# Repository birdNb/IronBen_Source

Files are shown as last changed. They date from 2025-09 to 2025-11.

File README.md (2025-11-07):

 # IronBen 四足轮腿机器人开源项目（一个普通本科生的毕业设计）

 作品展示：
https://www.bilibili.com/video/BV18B9oYQEoy/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

开源内容包括：
  项目相关的所有结构源文件Structure、相关的所有控制代码code（上下位机）、PCB硬件源文件Hardware。

本作品同步在立创星火计划开源。
![Uploading 星火计划-透底黑.png…]()

同时我们组建了作品复刻交流群，方便解答同学们在复刻过程中遇到的各种问题。
复刻交流群
24b2e99905efaedd1b54d2c5730278c4
 ![Uploading 24b2e99905efaedd1b54d2c5730278c4.png…]()

低成本、全3D打印、STM32双核控制、支持体感/键鼠/图传三模控制的四足轮腿机器人。

---

## 1. 项目亮点
- **供电简单**：6S航模电池24V一次到位，DJI A板直降12V供8个总线舵机，再转5V供逻辑。
- **结构友好**：Z轴非承力，轴承+M5长螺丝定位；小腿过孔+尼龙扎带，长期运行不松动。
- **全开源**：3D文件、PCB、固件、上位机一键下载

---

## 2. 快速参数
| 项目 | 规格 |
|---|---|
| 整机尺寸 | 320×360×180 mm |参考
| 自重 | ≈2.7 kg（含电池） |
| 动力电池 | 格氏6S航模锂电池  24V 跟我的3D打印件有 |
| 主控 | STM32F407VET6 + 扩展板 |
| 手柄 | STM32G431 + 1.3"LCD + 双摇杆 |
| 执行器 | 8×FashionStar总线舵机12V + 4×DJI M3508轮毂电机 |
| 传感器 | JY901S陀螺仪×2、LoRa 433MHz |
| 通讯 | UART×3 / CAN×2 / ESP-NOW / 2.4G |所用通讯波特率均为115200

---
## 3. 文件结构
IronBen/
├── Structure/          # STL&STEP，打印方向已标
│   ├── Leg/           # 小腿-大腿-关节
│   ├── Body/          # 上下盖板、骨架
│   └── Wheel/         # 轮毂适配器
├── Hardware/
│   ├── Gerber_ExtBoard/  # 扩展板
│   ├── Gerber_CoreBoard/ # F407核心板
│   └── 手柄
├── code/
│   ├── F407_Chassis/  # 底盘信号+关节控制
│   ├── M3508_DJI/     # 3508电机驱动
│   └── Bodyfeeling/   # 体感手柄
│   └── cac-master/    # Jetson Nano图传+键鼠遥控
## 4. 一键BOM
| 名称 | 数量 | 团购暗号 | 备注 |
|---|---|---|---|
| FashionStar总线舵机12V | 8+2备 | 找杨经理13924656166说"四足轮腿机器人"可以优惠 | 
淘宝链接：[https://item.taobao.com/item.htm?id=645793030775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](https://item.taobao.com/item.htm?id=645793030775&spm=a21xtw.29178619.0.0&skuId=5216441462419)

| DJI M3508+C620套装 | 4套 | DJI官方 | 已含电机、电调、螺丝 |
| JY901S陀螺仪 | 2 | 维特智能 | 机身×1手柄×1 |
| STM32G431核心板 | 1 |   手柄主控 |
| 1.3"圆角LCD | 1 | SPI接口 | 易碎 |
| LoRa邮票孔433M | 4 | 一次性买齐，同批次 | 避免频段不同 |
| 偏心震动马达 | 3 | 10mm | 手柄反馈 |
| 摇杆ALPS | 2 | 带按键 | 与PCB封装匹配 |

五金&耗材见下节，全部内六角，电动螺丝刀扭矩≤3档，**禁止螺纹胶**！

---

## 5. 五金&耗材清单
| 规格 | 数量 | 用途 | 工具提醒 |
|---|---|---|---|
| PLA+2.0 | 3卷 | 全身结构 | 0.3层厚，30%填充 |
| M2×5内六角 | 50+ | 舵盘-舵机-3D件 | 威克士2代≤3档 |
| M3×10自攻 | 40+ | 上下盖板 | 预攻丝，滑丝换件 |
| M4×10内六角 | 20 | 骨架主梁 | 对角锁 |
| M5×40内六角 | 4 | 轮子+小腿+轴承 | 配625ZZ轴承×8 |
| 尼龙扎带 | 1包 | 小腿抱紧舵机 | 消除长期应力 |
| 硅胶线16AWG | 50cm | 电池→DJI A板 | 防压降 |
| 硅胶线20AWG | 30cm | 12V母线 | 同上 |

---

## 6. 供电接线图
24V电池(XT90)
├─DJI A板(24→12V)──12V母线──8×舵机
└─扩展板DC-DC(12→5V)──5V逻辑──F407+传感器

---

## 7. 装机流程（10分钟上手）
1. **打印**：按STL默认方向，0.3mm，无支撑。
2. **电子预检**：
   - 空载测12V/5V/3.3V正常 → 再插舵机。
   - 舵机ID逐个烧写，顺序0-7（右前→左后）。
3. **机械**：
   - 先装轮子+轴承+M5×40，再装小腿→尼龙扎带抱紧。
   - 所有螺丝**对角预紧→3档最终拧紧**。
4. **通讯**：
   - LoRa四块同时上电，长按SET 3s绿灯快闪即同频。
   - CAN终端电阻DJI A板已带，扩展板**勿重复焊**。
5. **上电自检**：
   - 蜂鸣器"滴"→舵机蓝→绿灯→M3508微抖，完成。

---

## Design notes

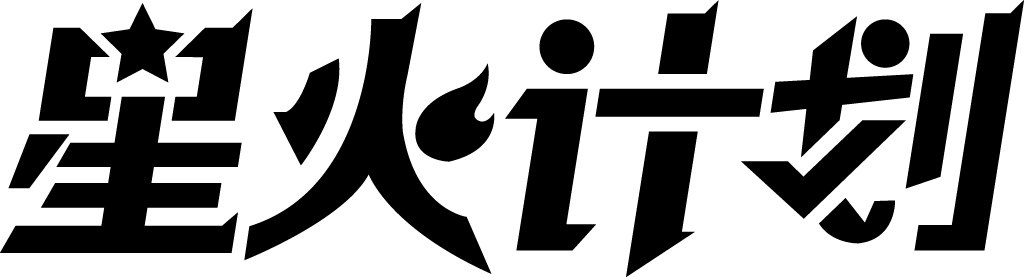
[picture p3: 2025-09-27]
星火计划-透底黑.png

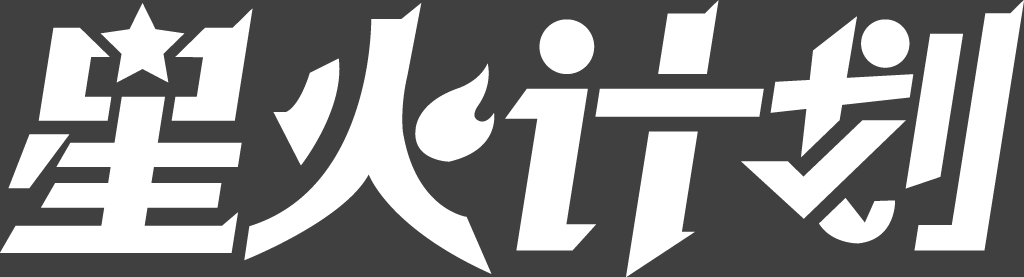
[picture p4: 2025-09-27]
星火计划-透底白.png

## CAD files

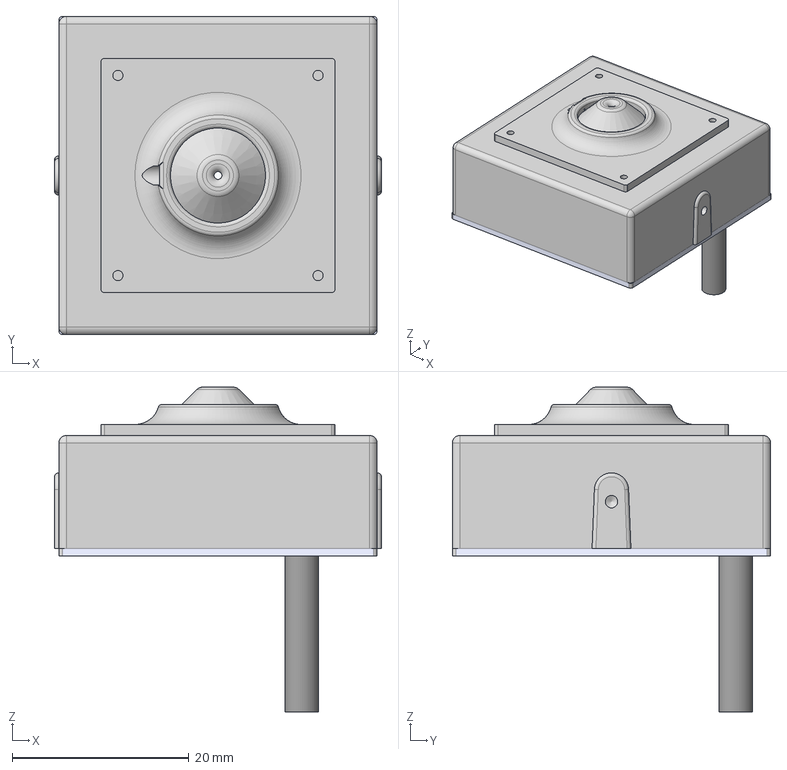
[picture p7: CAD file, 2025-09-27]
Structure/IronBen_print/摄像头.step
37.0 x 36.0 x 36.7 mm

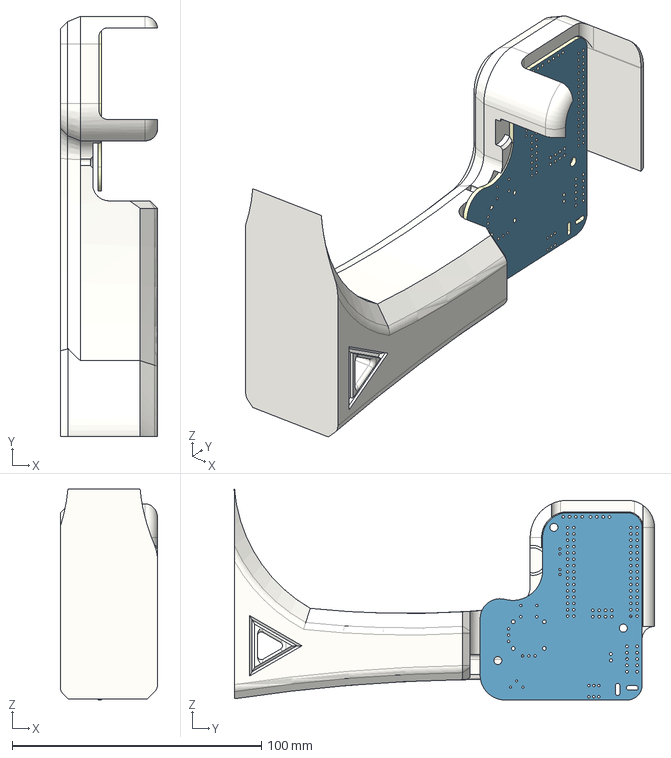
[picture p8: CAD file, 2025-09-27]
Structure/手柄.step
39.0 x 168.7 x 84.7 mm
手柄2.0
Board

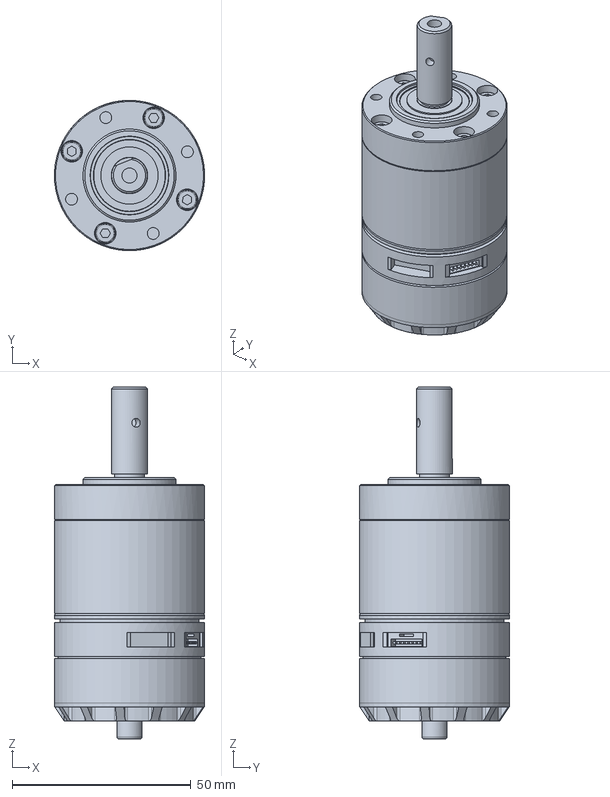
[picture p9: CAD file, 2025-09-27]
Structure/IronBen_print/3508电机.step
42.0 x 42.0 x 98.4 mm

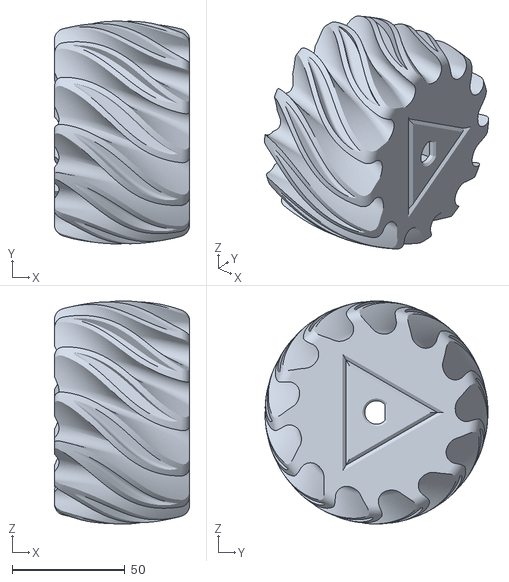
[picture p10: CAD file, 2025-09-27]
Structure/IronBen_print/轮本体.stl
60.0 x 98.9 x 99.0

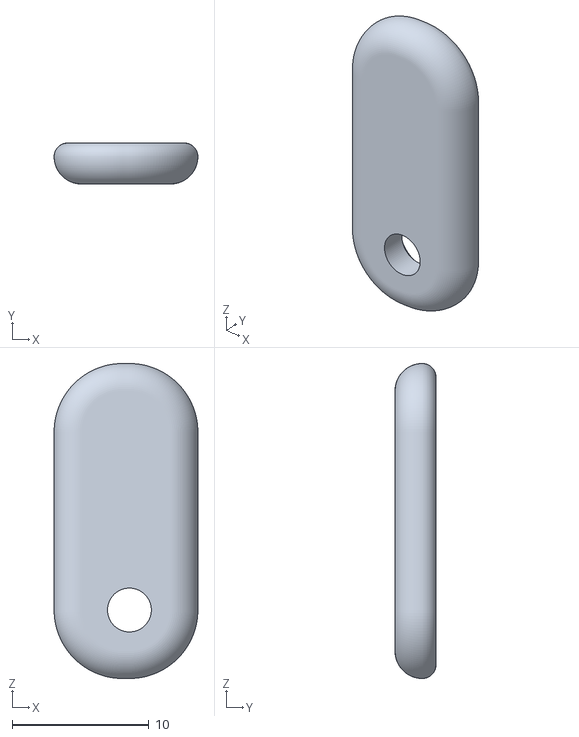
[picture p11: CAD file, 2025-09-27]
Structure/IronBen_print/旋转固定块.stl
10.5 x 3.00 x 23.0

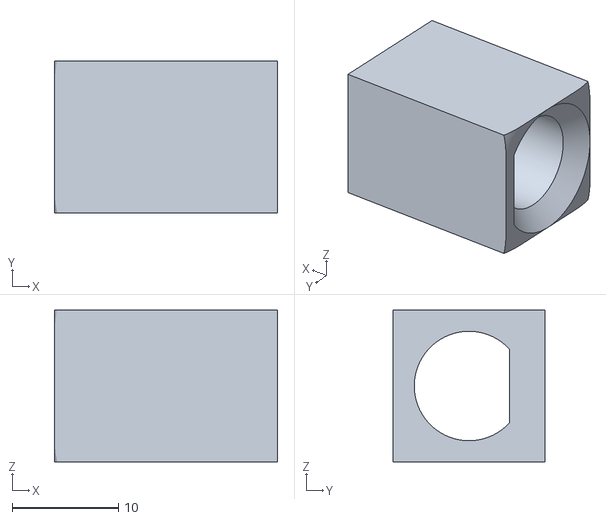
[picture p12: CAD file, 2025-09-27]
Structure/IronBen_print/旋转加强块.stl
21.0 x 14.3 x 14.3

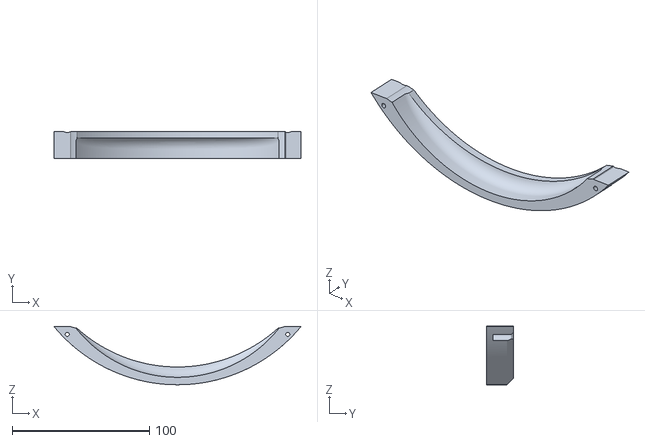
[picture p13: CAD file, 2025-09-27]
Structure/IronBen_print/后部眉盖.stl
180.0 x 20.0 x 42.7

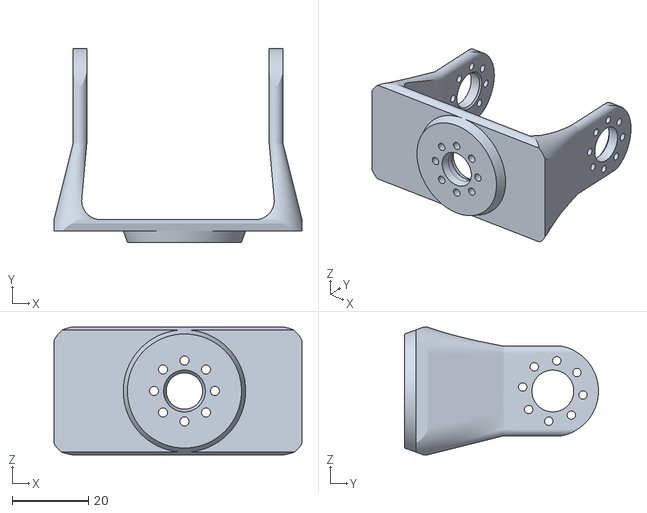
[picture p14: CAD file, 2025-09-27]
Structure/IronBen_print/云台T架.stl
65.2 x 51.0 x 33.6

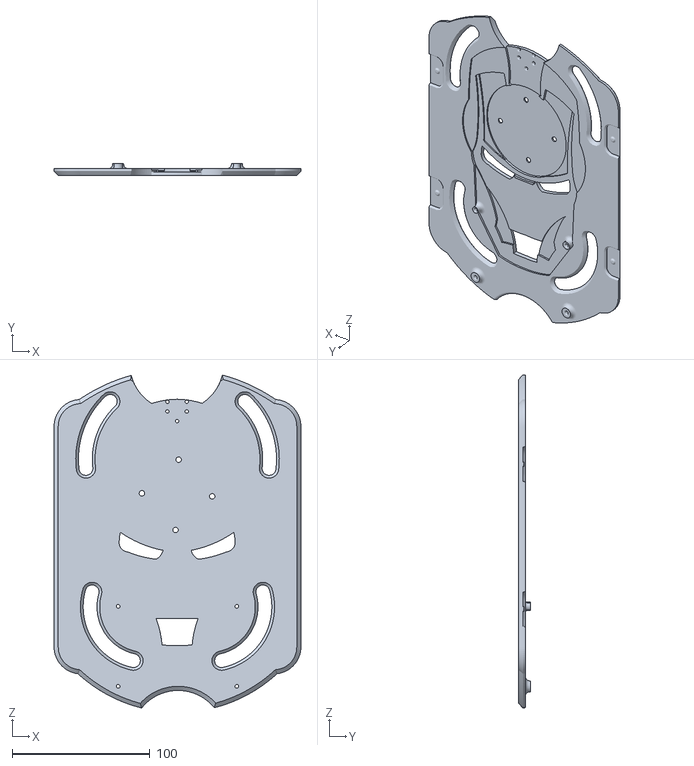
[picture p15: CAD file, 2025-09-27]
Structure/IronBen_print/顶板_jetson.stl
179.0 x 8.50 x 241.5

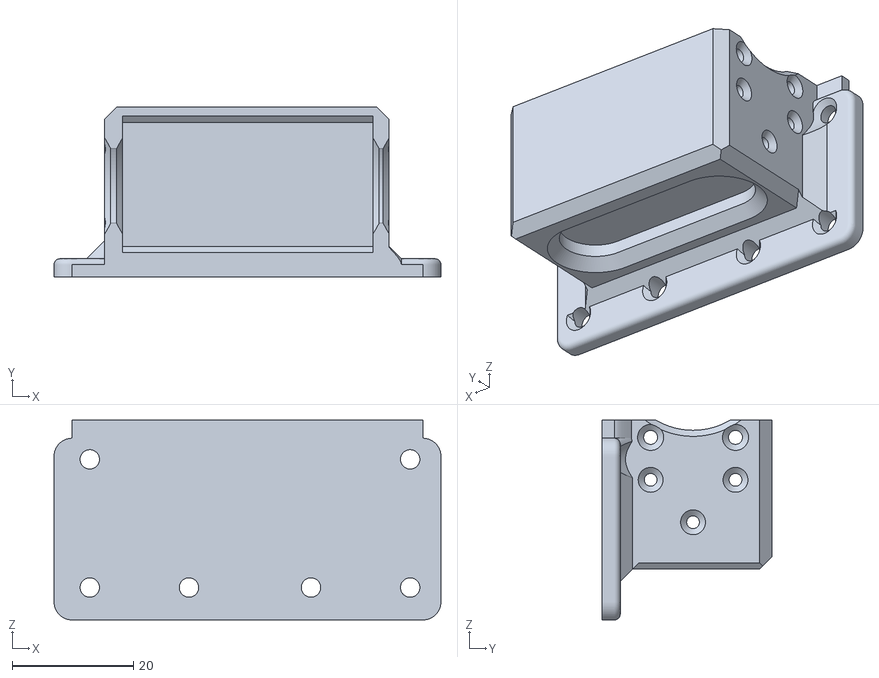
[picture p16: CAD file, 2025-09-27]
Structure/IronBen_print/舵机固定.stl
63.8 x 28.0 x 33.0

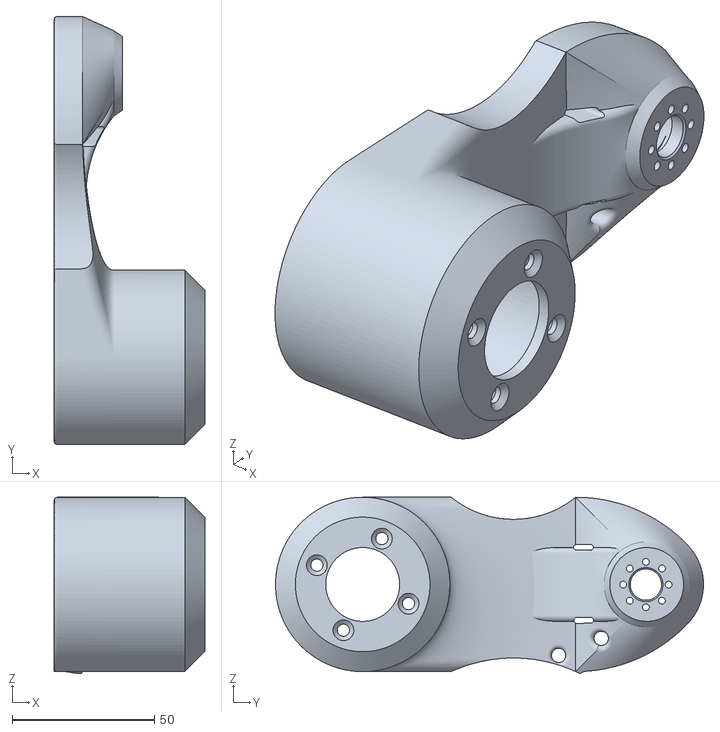
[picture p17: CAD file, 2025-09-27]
Structure/IronBen_print/左内.stl
53.0 x 150.7 x 62.1

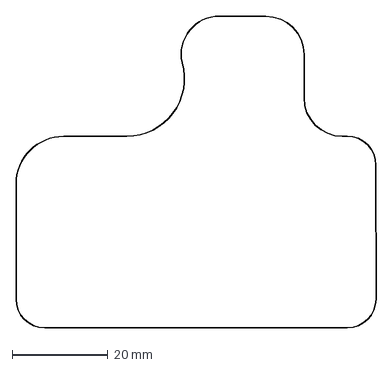
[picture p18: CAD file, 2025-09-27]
Structure/IronBen_print/handlepcb.dxf
75.2 x 65.1 mm

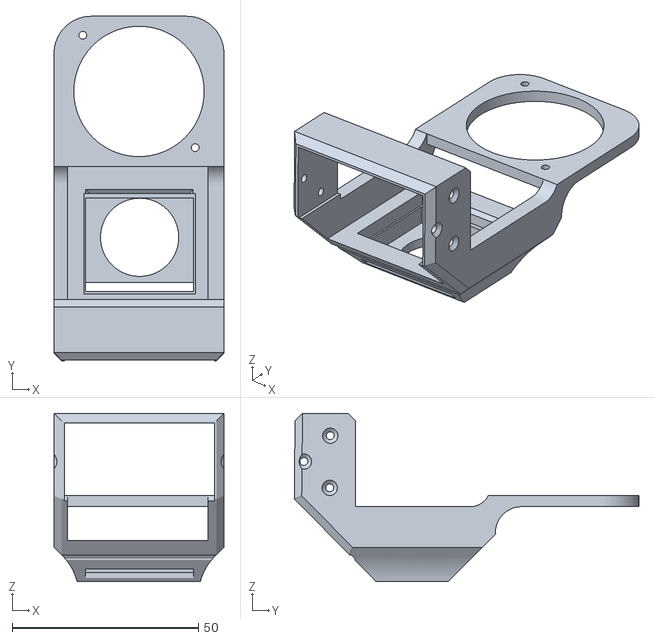
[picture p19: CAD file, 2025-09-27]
Structure/IronBen_print/镜头双摄.stl
45.7 x 92.5 x 45.2

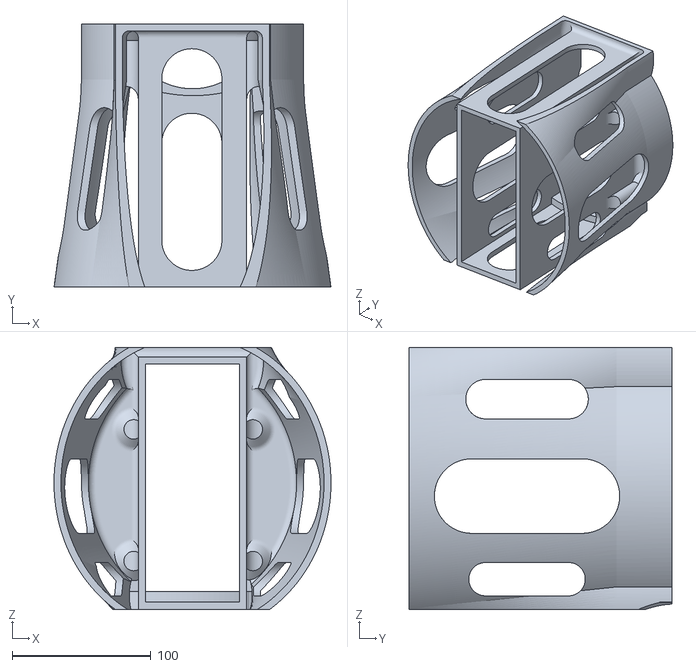
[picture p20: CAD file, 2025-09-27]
Structure/IronBen_print/调试底座.stl
200.0 x 190.0 x 189.2

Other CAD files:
Structure/IronBen_print/右内.stl
Structure/IronBen_print/左侧连接块.stl
Structure/IronBen_print/大腿金属打印.stl
Structure/IronBen_print/Bird-broad.dxf
Structure/IronBen_print/Bottom.stl
Structure/IronBen_print/PCB固定柱子.stl
Structure/IronBen_print/Top.stl
Structure/IronBen_print/pcb加电位器空间.dxf
Structure/IronBen_print/pcb板框.dxf
Structure/IronBen_print/三角-无方轴.stl
Structure/IronBen_print/上板.step
Structure/IronBen_print/上板.step.DXF
Structure/IronBen_print/前部底盘.stl
Structure/IronBen_print/前部眉盖.stl
Structure/IronBen_print/半球上盖.stl
Structure/IronBen_print/单腿 v116.stl
Structure/IronBen_print/单腿 v117.stl
Structure/IronBen_print/右侧连接块.stl
Structure/IronBen_print/后部底盘.step
Structure/IronBen_print/后部底盘.stl
Structure/IronBen_print/外侧合成舵盘.stl
Structure/IronBen_print/大腿.stl
Structure/IronBen_print/左内_准备加电机防沙罩.step
Structure/IronBen_print/扇叶轮_最新_11_30.step
Structure/IronBen_print/扇叶轮外侧.stl
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

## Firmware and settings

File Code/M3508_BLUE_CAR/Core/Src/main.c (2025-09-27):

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
/* Includes ------------------------------------------------------------------*/
#include "main.h"
#include "can.h"
#include "usart.h"
#include "gpio.h"

/* USER CODE BEGIN Includes */
#include "bsp_can.h"
#include "CAN_receive.h"
#include "bsp_Bluetooth.h"

#include "pid.h"
/* USER CODE END Includes */


/* USER CODE BEGIN PV */
pid_type_def motor0_pid,motor1_pid,motor2_pid,motor3_pid;	//声明PID数据结构体
const motor_measure_t *motor0_data;//声明电机结构体指针
const motor_measure_t *motor1_data;//声明电机结构体指针
const motor_measure_t *motor2_data;//声明电机结构体指针
const motor_measure_t *motor3_data;//声明电机结构体指针

int set_speed0 = 0;//目标速度
int set_speed1 = 0;//目标速度
int set_speed2 = 0;//目标速度
int set_speed3 = 0;//目标速度
const fp32 PID[3]={13,0.01,6};

/* USER CODE END PV */

void SystemClock_Config(void);
/* USER CODE BEGIN 0 */

void set_speed(int Vx,int Vy,int w)
{
	set_speed1= -(-Vx+Vy-w);//前右目标速度
	set_speed0= Vx+Vy+w;//前左目标速度
	set_speed2= -(Vx+Vy-w);//后右目标速度
	set_speed3= -Vx+Vy+w;//后左目标速度
	
	if(set_speed0>9000){set_speed0=9000;}else if(set_speed0==0){set_speed0=0;}else if(set_speed0<-9000){set_speed0=-9000;}
	if(set_speed1>9000){set_speed1=9000;}else if(set_speed1==0){set_speed1=0;}else if(set_speed1<-9000){set_speed1=-9000;}
	if(set_speed2>9000){set_speed2=9000;}else if(set_speed2==0){set_speed2=0;}else if(set_speed2<-9000){set_speed2=-9000;}
	if(set_speed3>9000){set_speed3=9000;}else if(set_speed3==0){set_speed3=0;}else if(set_speed3<-9000){set_speed3=-9000;}
	
}


/* USER CODE END 0 */

/**
  * @brief  The application entry point.
  * @retval int
  */
int main(void)
{
  /* USER CODE BEGIN 1 */
	blueData.mode = 1;
  /* USER CODE END 1 */

  /* MCU Configuration--------------------------------------------------------*/

  /* Reset of all peripherals, Initializes the Flash interface and the Systick. */
  HAL_Init();

  /* Configure the system clock */
  SystemClock_Config();

  /* Initialize all configured peripherals */
  MX_GPIO_Init();
  MX_CAN1_Init();
  MX_CAN2_Init();
  MX_UART7_Init();
  MX_USART2_UART_Init();
	MX_UART8_Init();
	MX_USART6_UART_Init();
  /* USER CODE BEGIN 2 */
	can_filter_init();
	
	HAL_GPIO_WritePin(GPIOH, GPIO_PIN_2, GPIO_PIN_SET);
	HAL_GPIO_WritePin(GPIOH, GPIO_PIN_3, GPIO_PIN_SET);
	HAL_GPIO_WritePin(GPIOH, GPIO_PIN_4, GPIO_PIN_SET);
	HAL_GPIO_WritePin(GPIOH, GPIO_PIN_5, GPIO_PIN_SET);
	HAL_GPIO_WritePin(GPIOF, GPIO_PIN_14, GPIO_PIN_RESET);
	HAL_GPIO_WritePin(GPIOE, GPIO_PIN_11, GPIO_PIN_RESET);

	PID_init(&motor0_pid,PID_POSITION,PID,16000,2000);//结构体，计算模式，参数，最大输出，最大积分输出
	PID_init(&motor1_pid,PID_POSITION,PID,16000,2000);//结构体，计算模式，参数，最大输出，最大积分输出
	PID_init(&motor2_pid,PID_POSITION,PID,16000,2000);//结构体，计算模式，参数，最大输出，最大积分输出
	PID_init(&motor3_pid,PID_POSITION,PID,16000,2000);//结构体，计算模式，参数，最大输出，最大积分输出
	
	motor0_data = get_chassis_motor_measure_point(0); //获取电机数据指针编号范围（0~3）	
	motor1_data = get_chassis_motor_measure_point(1); //获取电机数据指针编号范围（0~3）
	motor2_data = get_chassis_motor_measure_point(2); //获取电机数据指针编号范围（0~3）
	motor3_data = get_chassis_motor_measure_point(3); //获取电机数据指针编号范围（0~3）
//	printf("Init ok");
	
	Bluetooth_uart_init();
	HAL_Delay(10);
//	CAN_cmd_chassis_reset_ID();
//	HAL_Delay(5000);
//	CAN_cmd_chassis_reset_ID();

  /* USER CODE END 2 */

  /* Infinite loop */
  /* USER CODE BEGIN WHILE */
  while (1)
  {
//		CAN_cmd_chassis(1000, 1000, 1000, 1000);
		PID_calc(&motor0_pid,motor0_data->speed_rpm,set_speed0);//结构体，实际速度，设定速度
		PID_calc(&motor1_pid,motor1_data->speed_rpm,set_speed1);//结构体，实际速度，设定速度
		PID_calc(&motor2_pid,motor2_data->speed_rpm,set_speed2);//结构体，实际速度，设定速度
		PID_calc(&motor3_pid,motor3_data->speed_rpm,set_speed3);//结构体，实际速度，设定速度
		CAN_cmd_chassis(5000,5000,5000,5000);


//printf("%d,%d,%d,%d,%d,%d\r\n",set_speed0,set_speed1,motor0_data->speed_rpm,motor1_data->speed_rpm,motor2_data->speed_rpm,motor3_data->speed_rpm);
		
		HAL_Delay(2);
		
    /* USER CODE END WHILE */

    /* USER CODE BEGIN 3 */
  }
  /* USER CODE END 3 */
}

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


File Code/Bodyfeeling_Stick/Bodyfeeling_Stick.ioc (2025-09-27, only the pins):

Mcu.UserName=STM32G431RBTx
PA0.Signal=GPIO_Input
PA1.Signal=S_TIM2_CH2
PA10.Signal=USART1_RX
PA13.Signal=SYS_JTMS-SWDIO
PA14.Signal=SYS_JTCK-SWCLK
PA2.Signal=USART2_TX
PA3.Signal=USART2_RX
PA4.Signal=S_TIM3_CH2
PA5.Signal=SPI1_SCK
PA6.GPIO_Label=LCD_DC
PA6.Signal=GPIO_Output
PA7.Signal=SPI1_MOSI
PA8.GPIO_Label=LCD_BLK
PA8.Signal=GPIO_Output
PA9.Signal=USART1_TX
PB0.Signal=GPIO_Input
PB1.Signal=GPIO_Input
PB11.Signal=SharedAnalog_PB11
PB12.Signal=SharedAnalog_PB12
PB13.Signal=SPI2_SCK
PB14.Signal=SPI2_MISO
PB15.Signal=SPI2_MOSI
PB2.Signal=GPIO_Input
PB4.Signal=S_TIM3_CH1
PB5.Signal=GPIO_Input
PB6.Signal=GPIO_Input
PB7.Signal=GPIO_Input
PC1.Signal=SharedAnalog_PC1
PC11.GPIO_Label=LCD_RST
PC11.Signal=GPIO_Output
PC2.Signal=SharedAnalog_PC2
PC3.Signal=GPIO_Input
PC4.GPIO_Label=LCD_CS
PC4.Signal=GPIO_Output
PC6.Signal=GPIO_Output
PC8.Signal=S_TIM3_CH3
PC9.Signal=S_TIM3_CH4
PF0-OSC_IN.Signal=RCC_OSC_IN
PF1-OSC_OUT.Signal=RCC_OSC_OUT

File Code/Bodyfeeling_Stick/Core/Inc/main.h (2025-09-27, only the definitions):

#define LCD_DC_Pin GPIO_PIN_6
#define LCD_DC_GPIO_Port GPIOA
#define LCD_CS_Pin GPIO_PIN_4
#define LCD_CS_GPIO_Port GPIOC
#define LCD_BLK_Pin GPIO_PIN_8
#define LCD_BLK_GPIO_Port GPIOA
#define LCD_RST_Pin GPIO_PIN_11
#define LCD_RST_GPIO_Port GPIOC

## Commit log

2025-09-27 星火计划logo加入
2025-10-17 润色提交
2025-10-22 补齐F407代码

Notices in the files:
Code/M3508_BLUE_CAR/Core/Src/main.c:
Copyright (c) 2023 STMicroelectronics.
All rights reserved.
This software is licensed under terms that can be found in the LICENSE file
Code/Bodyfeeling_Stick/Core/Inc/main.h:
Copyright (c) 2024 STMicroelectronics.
